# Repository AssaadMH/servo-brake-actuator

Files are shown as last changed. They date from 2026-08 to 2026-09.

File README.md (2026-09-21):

# Fail-Safe Servo Brake Actuator
> A printed drum that lets one servo pull two bicycle brake cables — the mechanical answer to an electrical failure.
`2026` · `OpenSCAD` · `Mechanism design` · `FDM` · `Force analysis`

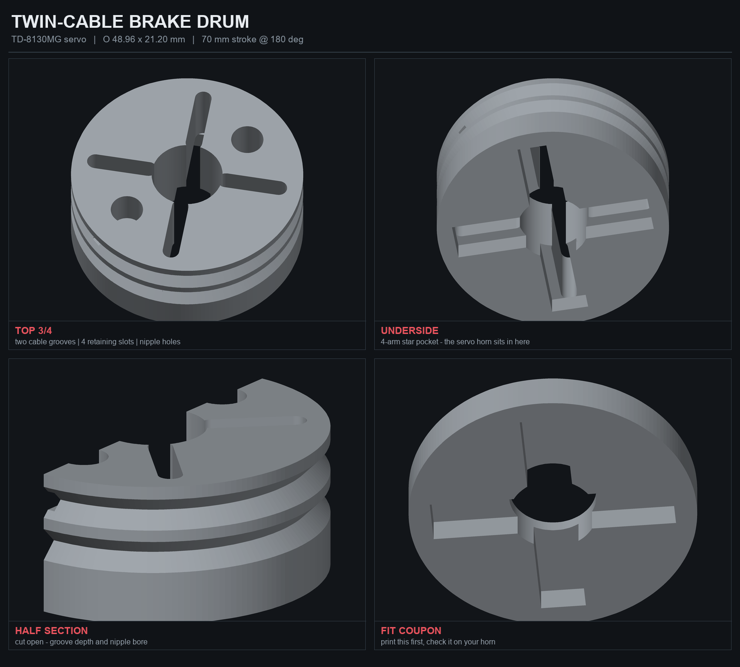
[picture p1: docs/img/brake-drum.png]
Fail-Safe Servo Brake Actuator


## Origin

Built at **IRIS Systems** during a 2026 engineering internship, as part of a team working on
the SHADOW autonomous vehicle programme. This repository covers the parts I worked on; the
wider programme is IRIS Systems' project. Published with their agreement.

## About

After the electrical hold-brake failure on SHADOW, the parking brake had to become purely mechanical. SHADOW was a team project and the failed electrical brake was the team’s work; the mechanical replacement described here is my contribution to it. The first working actuator uses a TD-8130MG servo to pull two bicycle brake cables simultaneously through a printed cable drum.

**The key design decision** is that the drum *captures the servo's stock metal horn* rather than reproducing its 25-tooth spline. A 25T spline printed in PLA strips under load — 30 kg·cm across 0.3 mm teeth on a 6 mm shaft is on the order of 100 kg of shear along the layer lines. A captured horn puts the torque into steel and reduces the plastic's job to holding it in place.

**Force analysis drove the geometry, and it has exactly one governing variable.** At a fixed sweep angle the drum diameter follows directly from the cable stroke, and the pull follows inversely from the diameter — so *stroke sets force, and nothing else does*. That makes the honest way to gain force counter-intuitive: shrink the drum. The current design uses a 44 mm stroke on a Ø30.8 drum for about 6.4 kg per cable in normal working conditions, roughly 10.7 kg at stall. An earlier, larger revision with a longer stroke was weaker for the same servo. Going smaller still is not free either — below about Ø28 the cable groove undercuts the very shoulder the cable nipple pulls against, leaving under a millimetre of plastic to carry the load.

**Both cable anchors sit 180° apart and wind the same way,** so the two pulls cancel as a couple instead of summing into a side load on the servo's output bearing. Cable housing stops and mounting blocks were designed alongside the drum — the pull is taken by a tongue bearing against a groove wall rather than by the clamp bolt — and laid out on a single print plate with a fit-test coupon beside the real part, so one print answers both questions.

**The slicer caught what the CAD did not.** Square cable grooves left the flange above them hanging as an unsupported ring, so they became 90° V-sheaves that self-support — and, as a bonus, seat the cable at exactly the design radius automatically. A second finding is worth keeping: the CAD kernel reported the solid as clean while the exported mesh carried ten non-manifold edges, because a derived dimension landed exactly on another feature's rim. **A kernel saying "simple: yes" does not mean the exported file is sound** — the STL itself has to be checked, which is why every part here goes through an STL sanity script and a G-code verification pass before it reaches the printer.

**The final drum is not servo-driven at all.** The servo version above proved the cable-pull principle, but the production part replaces the white worm wheel inside a Bosch window-lift motor (`0130821xxx`) with a printed wheel that carries the four-cable brake drum on the same hub — so the gearmotor’s own reduction does the pulling. The tooth count was recovered from photographs by unwrapping the rim into polar coordinates and taking a DFT of the tooth frequency: an unambiguous peak at 72. The live part, `gear60_v3`, runs 76 teeth on a 60.80 mm pitch diameter (62.40 mm across the tips), 2.00 mm tooth height and an 8 mm bore, on a split clamping hub with an M3 pinch bolt.

**One number decides whether it fits, and it is still open.** Centre distance follows the *pitch* circle alone, so growing the wheel to 60.80 mm moves the worm 1.60 mm further out — 33.00 mm stock becomes 34.60 mm. Shaving the tooth tips buys none of it back: an earlier revision truncated the addendum and the centre distance did not move at all. Against a 2.00 mm tooth height, 1.60 mm of interference is a jam rather than a tight mesh, so this wheel needs a deliberate housing modification and will not drop into a stock gearbox. That is a known, quantified constraint of the current design rather than a surprise waiting at assembly.

## Figures

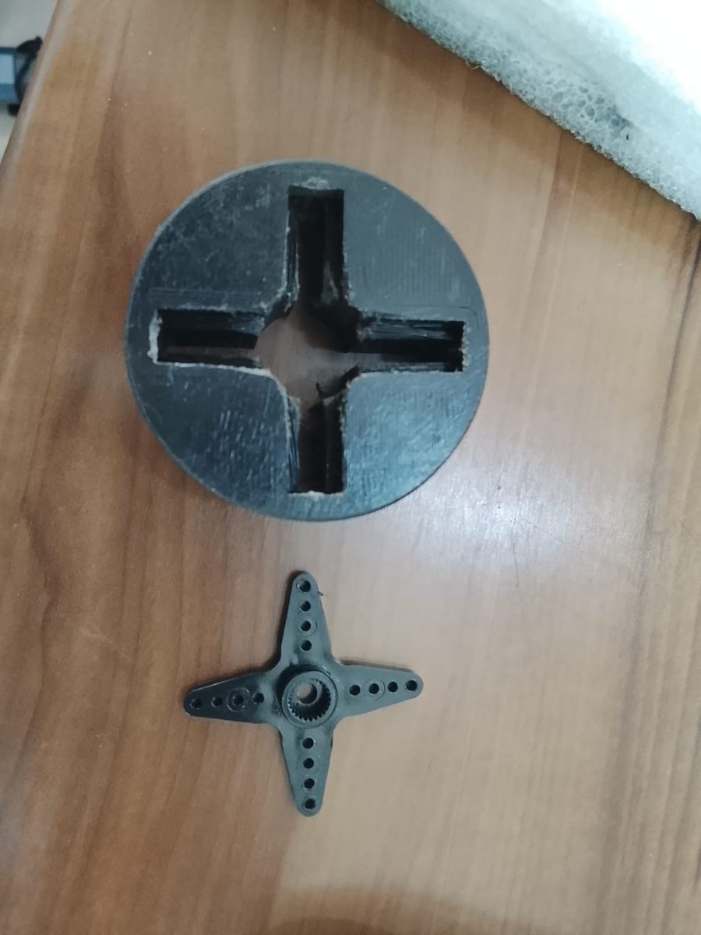
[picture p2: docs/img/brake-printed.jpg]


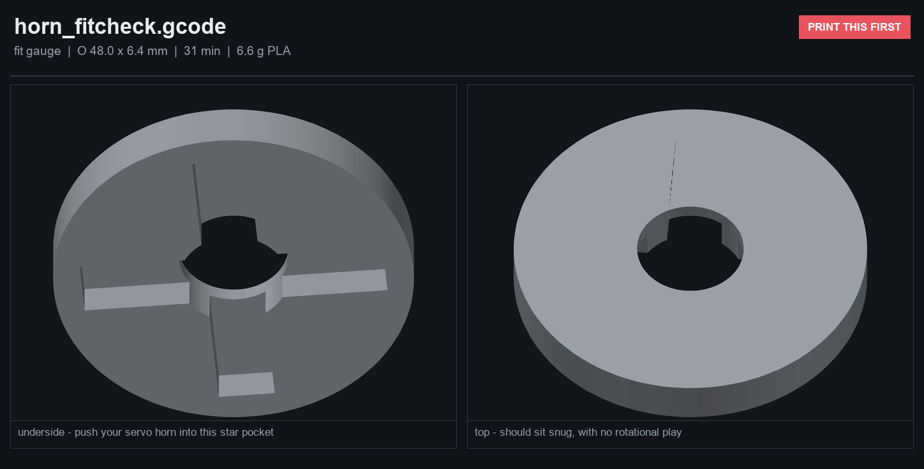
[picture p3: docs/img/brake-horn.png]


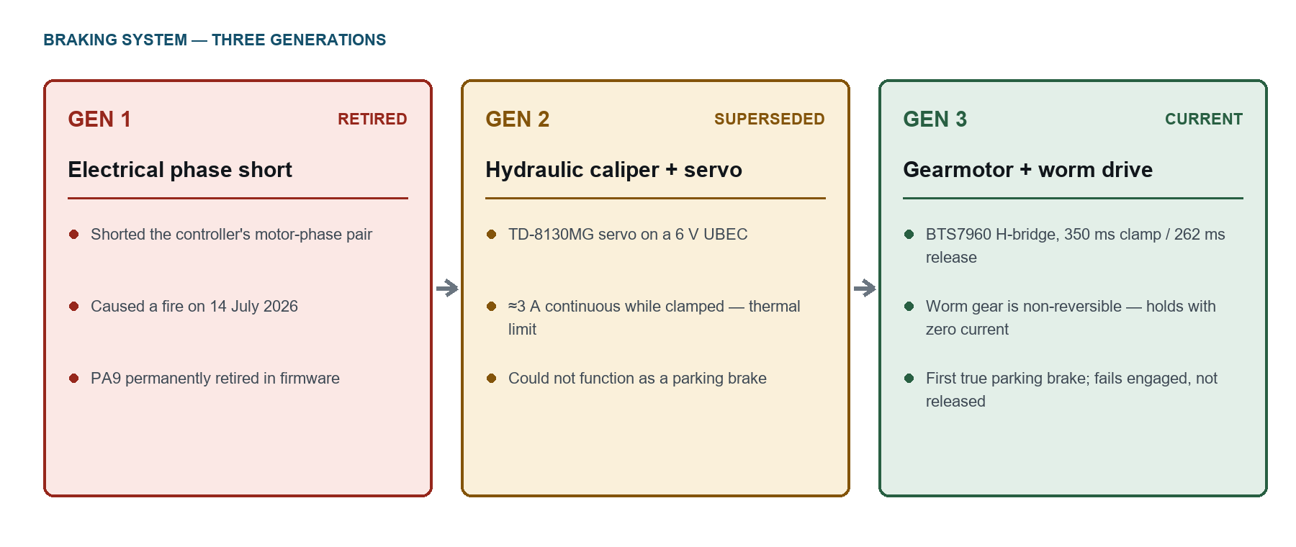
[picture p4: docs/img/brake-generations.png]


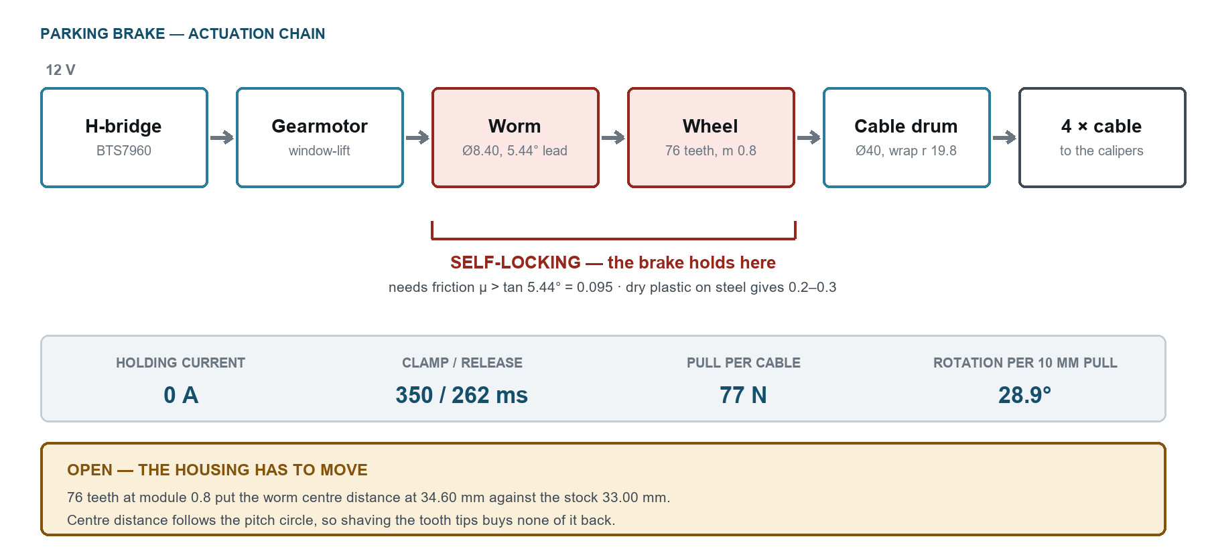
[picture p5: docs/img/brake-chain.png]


## Contents

```
design/
docs/
print/
worm-wheel/
```

## Notes

Not included in this repository: 18 generated/binary file(s), 10 mesh/binary over 2 MB file(s) - build caches, generated toolpaths and oversized binaries are kept out on purpose. The source they are generated from is here.

## Third-party work used here

This work was done as part of a team, and it builds on the following, which are **not** ours and are used under their own licences:

- **OpenSCAD** by OpenSCAD project — <https://openscad.org>

## Author

Lassaad Mahmoudi — <assaadmahmoudi0@gmail.com>  
https://linkedin.com/in/mahmoudi-assaad

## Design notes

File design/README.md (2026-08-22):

# Servo brake-cable drum — TD-8130MG  (rev B)

Pulls **two bicycle brake cables equally**, 70 mm of cable travel over 180° of servo rotation.
Ø47.36 × 19.50 mm. Sliced and ready to print.

## Print these

| File | Profile | Time | PLA |
|---|---|---|---|
| `horn_fitcheck.gcode` | gauge — 0.25 mm, 3 walls, 15 % | 31 m | 6.6 g |
| `servo_brake_drum.gcode` | structural — 0.15 mm, 5 walls, 55 % | 3 h 35 m | 26.0 g |

**Print `horn_fitcheck.gcode` first.** It is only the horn pocket. Push your black star horn into
it — snug, no rotational play. Slop there becomes brake slop later.

If it doesn't fit, measure the horn and edit these four lines at the top of the `.scad`, then
re-render and re-slice:

```
HORN_TIP   = 40.0;   // tip-to-tip across one pair of arms
HORN_ARM_W =  7.0;   // arm width, near the tip
HORN_T     =  4.0;   // arm thickness
HORN_BOSS  = 14.0;   // centre boss diameter
```

`CLR = 0.25` is the per-side clearance — 0.15 if your printer runs loose, 0.35 if it won't go on.

## Everything else in the folder

| File | What |
|---|---|
| `servo_brake_drum.scad` | parametric source, all knobs at the top |
| `servo_brake_drum.stl` / `horn_fitcheck.stl` | meshes — watertight, 1 shell, 0 non-manifold |
| `n2_pla_structural.ini` / `n2_pla_gauge.ini` | PrusaSlicer configs for the N2 |
| `check_stl.py` / `check_gcode.py` | verifiers (manifold + bed extents / E mode / G29) |
| `render_stl.py` / `make_sheet.py` | software renderer → `DRUM_overview.png` |
| `design.html` | the full illustrated spec sheet |

## Rebuilding after a change

```
set PART = "drum" (or "fit" / "cut") in the .scad, then:

C:\Users\HP\lidar_box\tools\openscad-2021.01\openscad.exe -o servo_brake_drum.stl servo_brake_drum.scad
prusa-slicer-console.exe --export-gcode --load n2_pla_structural.ini -o servo_brake_drum.gcode servo_brake_drum.stl
python check_stl.py servo_brake_drum.stl
python check_gcode.py servo_brake_drum.gcode
```

Three traps, all of which bit me here:

- Don't pass `-D` on the PowerShell command line — edit the knob in the file instead. If you script
  a temp copy, write it with `Set-Content -Encoding ascii`; `utf8` adds a BOM and OpenSCAD dies with
  *"Parser error: syntax error, line 1"*.
- **OpenSCAD's STL lands on disk seconds after the process exits.** Verify too quickly and you read
  the *previous* file and get a false confirmation. Check the timestamp.
- CGAL saying `Simple: yes` does not guarantee a clean STL. Run `check_stl.py`.

## What goes together, in order

1. Print the coupon, check the fit on your horn.
2. Screw the **stock star horn onto the servo** with its factory centre screw. That joint carries all
   30 kg·cm — the printed part never touches the spline.
3. Drop the drum over the horn. The star pocket underneath swallows it, rotated 45° from the nipples.
4. Retain with 2–4 M3 screws through the top slots, down into whichever horn holes line up.
   The slots run r = 8…19 mm so any hole pattern works.
5. Load the cables: nipple down its Ø6.6 hole from the top face, wire out sideways into its V.
   Defaults suit **flat-bar / MTB** barrels (6.6 × 8.0). For road pear nipples: `NIP_D = 7.6; NIP_H = 5.0`.

## Why it's shaped like this

- **V-sheaves, not square grooves.** A square groove leaves the flange above it hanging as a 3 mm
  cantilever ring in mid-air — the slicer flagged it as a collapsing overhang. 45° walls hold
  themselves up. Bonus: with the V apex at `R_EFF − CABLE_D/2`, the cable wedges itself at exactly
  the design radius.
- **Ø14.5 bore straight through**, same as the horn boss. A smaller bore leaves an unsupported ring
  at the pocket ceiling with nothing under it to print onto.
- **Nipples 180° apart** so the two ~66 N cable tensions form a couple that cancels, instead of
  adding into a 132 N side load on the servo's output bearing.

## Force budget — read this

| | |
|---|---|
| Servo torque | ~30 kg·cm |
| Cable centreline radius | 22.28 mm |
| Total pull | ~13.5 kg |
| **Per cable** | **~6.7 kg (66 N)** |

6.7 kg is a firm hand squeeze — **enough to pull a brake lever at the handlebar**, which is what a
70 mm stroke implies. **Not** enough to drive a caliper directly (a caliper wants 15–25 kg but only
~15 mm of travel).

If it's weak, shorten the stroke: `STROKE = 35` halves the drum and doubles the pull to ~13 kg per
cable. Every other dimension derives from that one number.

## You still need cable housing stops

This part only pulls the inner wire. The outer housing must be anchored to the aluminum plate at a
fixed point, aimed tangentially at each groove level. Without those two stops the housing just
compresses and nothing moves. **Not designed yet.**

## PLA caveat

PLA creeps under sustained load and softens near 55 °C. If this holds the brake applied for long
stretches, or lives in a closed enclosure, re-slice in PETG — same geometry, no changes.

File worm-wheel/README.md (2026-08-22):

# gear60 — 60 mm gear, Ø7 mm bore, 2.0 mm tooth height

Replacement for the white worm-wheel out of the Bosch window-lift motor
(`0130821xxx`) in the photos.

## Files

| File | What it is |
|---|---|
| `gear60.scad` | The parametric source — change everything here |
| `gear60_v2.scad` / `.stl` | ★ **CURRENT** — tip 60.60, bore 8, cable stations 20 mm higher, open cable chute. See [v2](#v2--gear60_v2scad). Print file `gear60_v2.gcode`. **Still needs the worm moved 0.8 mm.** |
| `cap60.scad` / `.stl` | ★ **Retaining cap** for the v2 drum — closes the open nipple pockets. Clamps on, needs no gear change. See [the cap](#the-retaining-cap--cap60scad). Print file `cap60.gcode` + one M3×14. |
| `test_cap_fit.scad` | Clash-checks the cap against the real exported gear mesh |
| `v2_profile.ini` | The PETG profile dumped out of the shipped v2 gcode — slice everything with this |
| `test_cable_route.scad` | Proves a cable can actually be fitted (needs a generated `_v2_sandbox.scad` — see [Re-generating](#re-generating)) |
| `gear60_drum4.stl` | Helical RH + 4-cable brake drum, the original 22 mm-tall part |
| `gear60_d608.scad` / `.stl` | Superseded by v2. Tip dia grown to 60.80 mm (z 74) — see [Bigger-OD variant](#bigger-od-variant--gear60_d608scad) |
| `gear60_d62.scad` | Superseded first pass at the above (z 76, tip 62.40). No STL. |
| `gear60_z72_m0.8_helical_RH.stl` | Plain wheel, helical 5.44° RH, no drum |
| `gear60_z72_m0.8_helical_LH.stl` | Same, left hand — if the worm turns out left-handed |
| `gear60_z72_m0.8_spur.stl` | Straight-cut fallback (helix 0) |
| `gear60_z72_m0.8_helical_RH_grub.stl` | Grub-screw hub instead of the clamp |
| `test_clamp.scad` | Geometric self-tests for the clamp (see below) |
| `preview_top/iso.png` | Renders |

Shaft is smooth, so the hub is a **split clamp with an M3 pinch bolt**.
See [The split clamping hub](#the-split-clamping-hub).

## What was measured from the photos

The rim was unwrapped into polar coordinates and the tooth frequency
extracted by DFT. The peak is unambiguous at **k = 72** across three
different sample radii (r = 840, 855, 870 px), so:

> **the original gear has 72 teeth.**

Teeth are fine-pitch, driven by the worm on the armature shaft. The
photos give no absolute scale, so the module was inferred from the tooth
count and then **confirmed by caliper** — see
[Module: CONFIRMED](#module-confirmed).

## The numbers — `gear60_z72_m0.8_helical_RH.stl`

Verified by re-reading the exported mesh, not from the script's own echo:

```
tip (outside) diameter   59.200 mm     <- matches the measured original
root diameter            55.200 mm
tooth height (whole)      2.000 mm
pitch diameter           57.600 mm
teeth                    72
axial module   m_x       0.80000       <- confirmed, 59.2 / 74
normal module  m_n       0.79640       <- derived, m_x * cos(helix)
helix angle              5.4403 deg    <- from the measured worm
helix hand               right (assumed - CHECK)
pressure angle           20°
circular pitch            2.513 mm
body bore                 7.20 mm  (7.0 + 0.20, non-gripping section)
clamp bore                7.10 mm  (7.0 + 0.10, this is what grips)
face width               10.00 mm
hub diameter             22.00 mm
total height             22.00 mm  (10 gear + 12 clamping hub)
slit                      1.20 mm wide, out to r = 18.5
jaw wall at the bore      7.45 mm
```

`ded_f = 1.5` is what buys the 2.00 mm depth — a standard 1.25 dedendum
would give 1.80 mm. On a worm drive a deeper root only adds tip
clearance, so this is safe either way.

Rebuild a z = 73 / Ø60.00 variant with `-D 'z=73'` if you ever want the
literal 60 mm for something else.

---

## The split clamping hub

The hub is a **C in cross-section**, 22 mm tall overall with 12 mm
projecting above the gear face. A 1.2 mm radial slit runs from the bore
out through the side, and an M3 socket-head pinch bolt pulls the two jaws
together. Friction round the whole shaft, no shaft modification needed.

```
   top view of the hub                side view
   ─────────────────────              ──────────
        ╭───────╮                     ┌────────┐  ← clamp hub, 12 mm
      ╭─┤ Ø7.1  ├─╮  ╔══╗       ══════┤        ├══════   z = 10..22
      │ │ bore  │ │══╣▓▓║ ear   teeth ▐└───┬──┘▌         z = 0..10
      ╰─┤       ├─╯  ╚══╝                Ø7.2 bore
        ╰───────╯     ↑
         ← slit →   M3 pinch bolt
         (1.2 mm)   crosses the slit
```

- Slit reaches **r = 18.5 mm**; the tooth roots start at r = 28 mm, so it
  never touches a tooth. The gear stays a full, unbroken 72-tooth ring —
  which is why the slit stops at the hub instead of running out through
  the rim the way a split pulley usually does.
- The slit root ends in a **Ø3 rounded relief** rather than a sharp
  corner. That is the crack starter on a printed part, so it gets a
  radius instead of an edge.
- The bolt seats land on **flat, parallel pads** (the stadium-shaped ear),
  not on the curved hub — Ø6.4 counterbore for the head on one side,
  Ø4.0 × 5 mm heat-set insert seat on the other.
- The clamp bore is **7.10 mm** while the gear body bore is 7.20 mm. The
  body section is deliberately looser so the clamp does the gripping and
  the gear still slides on easily.

### Why this beats the grub screws

Grub screws point-load two spots and dent the shaft; a clamp grips the
full circumference by friction. On a smooth shaft that is worth several
times the holding torque, and it does not chew up the shaft — so you can
still take it apart and reposition it.

### Fitting

1. Set the M3 insert in the ear (soldering iron ~200 °C for PETG, in
   slowly and straight).
2. Slide the gear on **with the bolt loose** — it should be a light slip
   fit. Do not force it; if it is tight, ream the bore rather than
   hammering, or raise `clamp_clear`.
3. Tighten the M3 gradually to roughly **1–1.5 Nm**. It will feel solid
   well before the 1.2 mm gap closes — the gap is *supposed* to stay
   partly open. If it bottoms out metal-to-metal before it grips, your
   bore printed oversize; drop `clamp_clear` to 0.05 and reprint.
4. Threadlock it. Car doors vibrate.

**Print it teeth-down, hub up.** That is not just about supports: the
C-section flexes circumferentially, so the bending stress runs *along*
the layers rather than trying to peel them apart. Printed on its side
this joint would delaminate at the back of the C.

### Verification

`test_clamp.scad` checks the things that are easy to get silently wrong,
each paired with a control probe that must give the opposite answer — a
probe that misses the part entirely would otherwise read as a pass:

| Test | Checks | Expect | Control | Expect |
|---|---|---|---|---|
| 1 | slit fully separates the jaws | empty | 2 | solid |
| 3 | head counterbore breaks through the flat | empty | 33 | solid |
| 4 | insert seat breaks through the far flat | empty | 44 | solid |
| 5 | ear stays clear of the tooth roots | empty | 55 | solid |

```bash
for T in 1 2 3 33 4 44 5 55; do "$OS" -D "TEST=$T" -o t.stl test_clamp.scad; done
```

All eight pass on the shipped geometry.

### Still want grub screws?

`hub_style = "grub"` gives 2 × M3 radial screws at 120° instead
(`gear60_z72_m0.8_helical_RH_grub.stl`). If you go that route, file two small flats
on the shaft where the tips land — otherwise it will spin under a stalled
worm.

---

## Module: CONFIRMED

Measured original tip diameter: **59.2 mm**, over the 72 teeth counted
from the photos.

```
m_n = OD / (z + 2) = 59.2 / 74 = 0.800   exactly
```

`m_n = 0.8` was an inference; it is now a measurement, and the two agree
to three decimal places. Tooth size is settled — **use the z = 72 file**.

That also means your "60 mm" was a rounded read of a 59.2 mm gear, and
"2 mm tooth height" of a standard 1.8 mm one (2.25 × 0.8). The shipped
`ded_f = 1.5` cuts the root 0.2 mm deeper than standard. That is
deliberate and safe on a worm drive — a deeper root only adds tip
clearance, it cannot cause interference. The addendum, which is what
actually sets the mesh, is fixed by the 59.2 mm tip diameter.

Derived, all now confirmed:

```
teeth            72        module      0.80
tip diameter     59.20     pitch dia   57.60
root diameter    55.20     base dia    54.13
circular pitch    2.513    ratio       72:1 with a single-start worm
```

## Helix: RESOLVED

Worm measured: **single start, 10.00 mm outside diameter.**

The lead angle is defined on the worm's **pitch** diameter, not its
outside diameter, and it uses the **axial** module:

```
d1    = worm_OD - 2*m_x       = 10.00 - 1.60      = 8.40 mm
helix = atan(starts * m_x / d1) = atan(0.8 / 8.4) = 5.4403 deg
```

> ### Correction
> An earlier version of this file gave 4.6 deg for a 10 mm single-start
> worm. That was wrong: it used the worm's **outside** diameter in place
> of its pitch diameter, and the normal module in place of the axial one.
> Both errors bias the angle low. The correct value is **5.4403 deg** —
> 0.87 deg higher. The table it came from is removed rather than
> corrected: the real worm is measured now, so the table is moot.

### What changed in the model

The tooth is now cut about the **axial / transverse** module, which is
the quantity that has to match the worm:

```
m_x  (axial = transverse)   0.80000   <- measured, must match the worm
m_n  (normal, derived)      0.79640   = m_x * cos(helix)
helix                       5.4403 deg, right hand (assumed)
twist over the 10 mm face   1.8947 deg
```

`m_x` is now the input and `m_n` is derived — the file previously had
that the wrong way round, which would have thrown the tip diameter
0.18 mm out as soon as a helix was applied. All three targets still land
exactly: tip 59.200, root 55.200, tooth height 2.000.

`slices` also no longer bottoms out at 2 for a small twist, which had
been leaving the helical flank as two straight bands. It is driven off
the face width now (351 z-levels in the mesh instead of 3).

### Verified in the mesh

The tooth phase was measured at the bottom face and again at the top,
as a circular mean folded into one 5 deg tooth pitch:

| Build | Measured twist, bottom -> top |
|---|---|
| helical RH | +1.8947 deg (counter-clockwise rising = right hand) |
| helical LH | -1.8947 deg (exact mirror) |
| spur | +0.0000 deg |

Predicted 1.8947 deg. Magnitude matches to four decimals, the hand
mirrors, and the spur control sits at zero.

### WARNING — hand is the one thing left to check

**A right-hand wheel will not mesh with a left-hand worm.** The hand is
not visible in your photos, so both are built.

Look at the worm from the side: if the threads climb left-to-right like
an ordinary screw or bolt, it is **right hand** -> use
`gear60_z72_m0.8_helical_RH.stl`. If they climb right-to-left, use the
`_LH` file. Most automotive worms are right-hand, which is why RH is the
default — but check, do not assume.

If you would rather not gamble, print `gear60_z72_m0.8_spur.stl` first as
a test fit. It will turn against either hand, just noisily.

### Honest limitation

This is a **cylindrical helical wheel, not a throated (globoid) one**. A
proper worm wheel is hollowed to wrap around the worm, giving line
contact along the thread. This one meets the worm on a short contact
patch instead. That matches what the original appears to be — its rim
looked flat in your photos, not throated — and a throated form is not
realistically printable at 0.8 module. It is the reason to expect a
service life below the moulded original's.

### Which STL?

**`gear60_z72_m0.8_helical_RH.stl`** — dimensional match to the original
(same 72 teeth, same module, same tip diameter, so ratio and centre
distance are unchanged) plus the 5.4403 deg helix the measured worm
calls for. Right hand.

Swap to `_LH` if the worm turns out left-handed, or `_spur` for a
hand-agnostic test fit.

A 73-tooth / 60.00 mm variant is no longer shipped — it only made sense
while 60 mm was believed to be the target. Rebuild it with
`-D 'z=73'` if you ever want it; note the extra tooth pushes the pitch
radius out 0.4 mm and will bind in the stock housing.

---

## Brake cable drum — 4 cables

Turns the wheel into a parking-brake actuator. The worm drive is
self-locking, so it holds cable tension with the power off.

```
                    stations at 45 / 135 / 225 / 315 deg
              nipple pocket d7.6              cable groove
                     |                             |
        z=22  _______v_____________________________v____
             |   o       o                              |  <- drum skirt
             |         COLLAR d22 (clamp)               |     d40, wall 3.5
   groove -> |=========================================||     
        z=13 |______   web 3.0   ______________________|
   gear face |################ GEAR BODY ##############|  z=10
        z=0  |#########################################|
```

| | |
|---|---|
| Drum outside dia | 40.00 mm |
| Skirt wall | 3.50 mm |
| Cable groove | 2.60 wide x 1.00 deep, floor at r 19.0 |
| Effective wrap radius | 19.8 mm |
| Nipple pocket | d7.6 x 9 deep, centre r 14.8, opens at the top face |
| Wire slot | 2.4 wide, tangential, at groove level |
| Stations | 4, at 45 / 135 / 225 / 315 deg |
| Rotation for 10 mm pull | 28.9 deg |
| Overall height | 22.00 mm — unchanged |

Stations sit at 45 deg so they stay clear of the slit and the bolt
access window, both at 0 deg. At 28.9 deg of travel and 90 deg spacing,
no cable ever reaches its neighbour's station.

### Two things the geometry forced

**The drum is a skirt, not a solid boss.** Growing the hub to a solid
d40 would take the clamp jaw wall from 7.45 to 16.45 mm. Closing
stiffness goes as t^3, so that is **10.8x stiffer** — the M3 pinch bolt
would never move it. The clamp collar stays at d22 and the drum is a
3.5 mm skirt tied to it by a 3 mm web, so the part that has to flex is
still the slim one.

**Each station needs a boss.** Above the web, the space between the d22
collar and the d33 skirt bore is open air. A pocket cut there would not
be a socket at all — the nipple would sit loose in a gap. Each station
gets a local boss spanning collar to skirt, which also ties the skirt
back in.

The slit and the bolt counterbore both run out through the skirt. They
have to: a slit that stops at the collar would leave the skirt welding
the jaws shut, and a bolt with no window would be unreachable.

### Force and stroke

Cable tension is torque / 19.8 mm, shared over 4 cables:

| Gear torque | Total pull | Per cable |
|---|---|---|
| 2 Nm | 101 N | 25 N (2.6 kgf) |
| 4 Nm | 202 N | 51 N (5.1 kgf) |
| 6 Nm | 303 N | 77 N (7.7 kgf) |
| 8 Nm | 404 N | 101 N (10.3 kgf) |

Shrink `drum_d` for more force and less stroke; the two trade directly.

### Self-locking margin — check this

The brake holds with the power off only while the worm cannot be
back-driven. That needs friction coefficient > `tan(5.44 deg)` = **0.095**:

| mu | Friction angle | |
|---|---|---|
| 0.05 well-greased steel/steel | 2.9 deg | **BACK-DRIVES** |
| 0.10 greased steel/plastic | 5.7 deg | holds, barely |
| 0.15 lightly oiled | 8.5 deg | holds |
| 0.25 dry steel/plastic | 14.0 deg | holds |

**The margin is thin.** A 5.44 deg lead sits right on the boundary, so do
not over-grease the worm. A plastic wheel on a steel worm runs at
mu 0.2-0.3 dry and holds comfortably; flood it with low-friction grease
and it can creep. Test it loaded before trusting it as a parking brake.

### Cable tensioning

The pear nipple seats in a fixed pocket, so tension is not adjusted at
the drum. That is normal and correct — set it at the caliper end, where
the bare wire is clamped, and use a standard **inline barrel adjuster**
per cable for fine independent trim. Roughly 10 mm of adjustment each,
which matches the stroke.

Stepped seats in the drum were considered and rejected: a d7.0 nipple
needs seats 8 mm apart to stay distinct, and 8 mm steps are useless
against a 10 mm stroke. A printed threaded adjuster was rejected too —
it would put the full brake load on a plastic thread.

### Assembly

Feed each wire in through the slot from the drum surface, then drop the
nipple into its pocket from the top. The slot is a buried channel at
groove level, so the wire stays captive once seated.

### Verification

| Probe | Checks | Expect | Control | Expect |
|---|---|---|---|---|
| 10 | Nipple pocket is a real socket | empty | 100 | solid |
| 11 | Wire slot reaches the drum surface | empty | 110 | solid |
| 12 | Skirt sits on solid material | solid | 120 | empty |
| 13 | Hex key reaches the pinch bolt | empty | 130 | solid |

All pass, alongside the original 8 clamp probes.

---

## Bigger-OD variant — `gear60_d608.scad`

Tip dia **60.80 mm**, up from 59.20. At `m_x = 0.8` the tip diameter only
moves in **1.60 mm steps** (one whole tooth adds `2*m_x`), and the module
is the one number that must stay 0.8 to match the worm — so 60.80 is not
an approximation, it is exactly `z = 74`:

| | stock `gear60_drum4` | `gear60_d608` |
|---|---|---|
| teeth | 72 | **74** |
| tip dia | 59.20 mm | **60.80 mm** (+1.60) |
| pitch dia | 57.60 mm | 59.20 mm |
| root dia | 55.20 mm | 56.80 mm |
| module / pressure angle | 0.8 / 20° | unchanged |
| helix | 5.4403° RH | unchanged (twist re-derived, −1.84°) |
| tooth height | 2.00 mm | unchanged |
| bore, hub, clamp, drum | — | all unchanged |
| overall height | 22.00 mm | 22.00 mm |
| ratio with a 1-start worm | 72:1 | 74:1 |
| slice (same PETG profile) | 3 h 29 m, 9756 mm | 3 h 33 m, 9958 mm |

**This still breaks the stock mesh.** Worm centre distance is
`(d_worm_pitch + d_wheel_pitch)/2` = `(8.40 + 57.60)/2` = **33.00 mm**
stock, but **33.80 mm** here. The worm must move **0.80 mm** further from
the wheel axis (or the wheel shaft moves the same amount). That is half
the shift of the abandoned 62.40 version, but 0.80 mm of interference
against a 2.00 mm tooth height is still a jam, not a tight mesh. No
amount of gear geometry absorbs it — it is a housing change.

The variant is a 3-line file that `include`s `gear60.scad` and overrides
`z`, so the base design stays the reference part.

### The z=74 degeneracy — fixed in `gear60.scad`

z=74 originally rendered at **genus 12** where 72, 73, 75 and 76 all gave
13. `stlcheck` found why: a **second shell — 6 triangles, zero volume, at
z=10.00, x=16.50**, i.e. exactly on the gear top face at the drum skirt's
inner wall. The drum lands *on* the gear face, so the skirt, web and boss
bottoms were all coplanar with the gear top: three coincident faces in one
union, and at that particular tooth count the tessellation threw off a
flake.

`drum_body()` now sinks the drum `eps = 0.01` into the gear (heights carry
the same `+eps`, so the top face stays at exactly 22.00). The overlap is
buried in solid material — **volume is unchanged at 31185.94 mm³ for the
stock part** — and 72/73/74/75/76 now all render as one shell, genus 13.
Another instance of the rule from the drum project: *keep derived
dimensions from coinciding exactly.*

All 16 probes in `test_clamp.scad` return identical results for z=72 and
z=74, controls included. The "long bridging extrusions" slicer notice is
the drum web and appears on the stock part too.

**Note on probe 4.** It reports *solid* where the table below says empty —
on the stock gear as well. Not a defect: the probe runs outward from the
ear flat at x=12 and clips the **315° cable boss**, which was added after
these 8 clamp probes were written. With `drum=false` probe 4 is empty, so
the insert seat is open as designed.

---

## v2 — `gear60_v2.scad`  (2026-08-08, current print file)

Four changes on top of `d608`. Print file: **`gear60_v2.gcode`**, 5 h 32 m,
38.36 cm³ (~49 g PETG), 42 mm tall.

| | `gear60_d608` | **`gear60_v2`** |
|---|---|---|
| teeth | 74 | 74 (unchanged) |
| **tip dia** | 60.80 mm | **60.60 mm** |
| addendum factor | 1.000 | **0.875** |
| pitch dia | 59.20 mm | 59.20 mm (unchanged) |
| root dia | 56.80 mm | 56.80 mm (unchanged) |
| tooth height | 2.00 mm | 1.90 mm |
| **bore (nominal shaft)** | 7.0 | **8.0** → 8.20 body / 8.10 clamp |
| jaw wall at bore | 7.45 mm | 6.95 mm |
| **hub_ext / total height** | 12 / **22 mm** | 32 / **42 mm** |
| **groove (cable) height** | z = 16 | **z = 36** (+20) |
| nipple pockets | z 13…22 | z 33…42 |
| pinch bolt | z = 16 | z = 26 |
| **cable loading** | closed tunnel | **open chute to the top face** |
| slice | 3 h 33 m | **5 h 32 m** |

### 1. Why 60.60 is an addendum change, not a tooth change

`m_x = 0.8` is the worm's axial module and cannot move; tooth count moves
the tip dia in 1.60 mm steps, so **60.60 is unreachable by adding teeth**.
It is reached by truncating the addendum instead — `add_f 1.000 → 0.875`
takes 0.10 mm off every tooth tip:

```
tip   60.80 → 60.60      pitch 59.20 → 59.20 (UNCHANGED)
root  56.80 → 56.80      tooth ht 2.00 → 1.90
```

**Consequence to be clear about: this does not fix the mesh problem.**
The pitch circle is what sets centre distance, and it did not move — the
worm still has to sit at **33.80 mm** instead of the stock 33.00 mm. The
0.80 mm housing shift from the d608 version is still outstanding. Shorter
tips relieve *tip* interference very slightly and nothing else.

### 2. Bore 8 mm

`bore_d` is the **nominal shaft** size, so the part comes out 8.20 through
the gear body and 8.10 in the clamp section, which then pinches down onto
a true 8.00 shaft. Same convention the 7 mm version used (7.20 / 7.10).
If the requirement is instead that the *hole measure* 8.00, set
`bore_d = 7.9`.

### 3. Cable stations 20 mm higher

The whole collar grows — `hub_ext 12 → 32` — so the skirt, the ear, the
slit and the four bosses all travel up together and the part is 42 mm
tall. The groove follows (`groove_z 16 → 36`) and the nipple pockets stay
9 mm down from the top face. The pinch bolt lands at z = 26, which also
gets it out of the groove it used to share a height with.

**Watch the overturning moment.** 4 × ~66 N now pulls 36 mm above the gear
face instead of 16 mm — roughly **2.2× the tilting moment** on an 8 mm
shaft and on a single M3 pinch bolt. If the collar ever cocks or walks on
the shaft, that is the reason, and a second pinch bolt higher up the
collar is the fix.

### 4. A route the cable can actually get in by — `wire_entry`

The first build could not be cabled by hand: the nipple pocket was blind
from the top and the wire slot was a **closed tunnel** at groove level, so
the only way in was to thread the free end of the cable in from outside
and pull the nipple down the pocket.

`wire_entry = true` (new in `gear60.scad`, now the default) runs that same
tangential slot on up to the top face as an open 2.4 mm chute. Drop the
nipple down its pocket, let the wire fall sideways into the notch, and it
seats itself in the groove.

The anchor is not weakened where it matters: the nipple is Ø7.0 against a
2.4 mm gap, so it still cannot escape sideways, and the load is still
carried by the two 2.6 mm lands either side of the slot — which is where
it was carried before. Only the material *above* the slot is gone, and it
was never in the load path (the pull is horizontal).

### Verification

- **1 shell, solid, 51 355.13 mm³**, bbox exactly 60.60 × 60.60 × 42.00
  (`stlcheck.py`).
- **Genus 3 at z = 73, 74 and 75** — stable across neighbours, so no
  repeat of the z=74 flake. (13 → 3 is expected: 8 handles disappear when
  the four wire tunnels become open notches, and 2 more when the groove
  moves away from the pinch-bolt counterbore.)
- `test_cable_route.scad` sweeps both loading motions — the Ø7.0 nipple
  falling down its pocket and the 1.6 mm wire falling down the chute —
  and intersects them with the part. **Empty = the route is clear.**
  It is proven sensitive: re-render the sandbox with `wire_entry=false`
  and it returns **4 × ~66 mm³ of obstruction at z 37.30…42.00**, exactly
  the roof the chute removes.
- Slicer profile is the one dumped out of `gear60_drum4_d608.gcode`;
  re-slicing the d608 STL with it reproduced the shipped **3 h 33 m 12 s**
  exactly, so it is a faithful control. v2 gcode verified on-bed
  (113–187 mm of a 300 mm bed), absolute E, no G29, top layer at 42.00.

---

## The retaining cap — `cap60.scad`  (2026-08-11)

`wire_entry = true` deliberately took the roof off the four nipple pockets
so the cables could be dropped in by hand. Nothing then stops a nipple
lifting back out when its cable goes slack. `cap60` closes them.

**It needs no change to the gear.** It clamps onto features that already
exist on `gear60_v2` as printed. Print file: **`cap60.gcode`**, 32 m 28 s,
4180.72 mm³, plus one **M3 × 14** screw.

| | |
|---|---|
| lid | OD 44.30, ID 22.60, 2.40 thick — sits on the top face at z 42.00 |
| skirt | bore 40.30 (0.15 radial slip on the Ø40 drum), 4.20 tall |
| skirt occupies | part z **37.80…42.00** — 0.50 clear of the groove top |
| split | 1.80 gap at **180°**, deliberately not at the gear slit's 0° |
| lugs | 6.00 × 6.00, 13.80 across the pair, M3 Ø3.40 / Ø2.90 thread-forming |
| lead-in | 0.60 chamfer at the skirt mouth |

### Why it clamps from outside

The collar is a **split clamp**. Anything gripping the drum rigidly and
bridging the slit stiffens the jaws and stops the M3 pinch bolt gripping
the shaft — the same reason the drum is a thin skirt and not a solid boss.
Clamping the *outside* squeezes in the **same direction the pinch bolt
works**, so it assists rather than fights, and the cap is itself split, so
it is a C-clip and not a hoop.

The centre is left open (ID 22.60), so it does not matter whether the
shaft protrudes past the top face or stops short of it.

There are only 4.70 mm of clean drum OD to grip — z 37.30 (groove top) to
42.00 — and nothing at all lives outboard of r 20 in that band. The
pinch-bolt counterbore does exit at y = 22, but at z = 26, eleven
millimetres below.

### ★ The wire chute is TANGENTIAL, not radial

The first cut of this cap keyed itself with a tab at each station angle,
dropping into the wire chute. `test_cap_fit.scad` rejected it —
**4 × 8.73 mm³ of interference at exactly 45/135/225/315, z 37.80…42.00.**

`gear60.scad` builds the chute as

```
translate([nip_r,0,z]) rotate([0,0,90]) translate([0,-w/2,0]) cube([r_o+4,w,h])
```

which is the strip **x 13.60…16.00, y 0…24** — it leaves the pocket
*sideways* in +Y and only crosses the OD **36.87°…47.16° away from its own
station**. At the station angle the drum OD is solid material. "Leaves the
pocket tangentially" in the source comment meant exactly that.

Tabs are off (`tabs = false`). Keying it properly would need an oblique
slab following those walls, for no gain: the cap is an annulus, so it
covers all four pockets at any rotation, and the M3 lug is what retains it.

### Verification

- Cap mesh: **1 shell, solid, 4180.72 mm³**, bbox 6.60 tall (`stlcheck.py`).
- `test_cap_fit.scad` intersects the cap, at its seat, with the **real
  exported gear mesh** — not with a re-derived model. **Empty**: every
  component comes back at 0.00 mm³, which is the lid underside resting
  coplanar on the top face at z = 42.00, as intended.
- **Proven sensitive**: `-D drop=1.5` sinks the cap into the cable groove
  and it returns **636 mm³ across 9 bodies**. Without that control an
  "empty" result would mean nothing.
- Sliced from `v2_profile.ini`, the profile dumped out of the shipped v2
  gcode, so the cap prints on the same settings as the gear.

### Assembly

Cable the drum as before, drop the cap on, and nip the M3 up until it
stops turning by hand. It lifts straight off again to re-cable. Do not
overtighten — the drum skirt is only 3.5 mm thick and the job is retaining
a slack nipple, not carrying load.

---

## Re-generating

```bash
OS="/c/Users/HP/Tools/openscad-nightly/OpenSCAD-2026.07.20-x86-64/openscad.exe"
"$OS" --backend=Manifold -D 'm_n=0.82' -D 'z=72' -D 'helix=8' \
      -o gear_custom.stl gear60.scad
```

Every parameter is overridable with `-D`. The script echoes the resulting
pitch/tip/root diameters and tooth height so you can check them before
slicing.

## Printing

- Print **flat on the toothed face**, no supports. The web recess and the
  bore are the only overhangs and both are vertical.
- 0.12–0.16 mm layers. At 2.51 mm circular pitch the teeth are small —
  a 0.4 mm nozzle is the practical floor, 0.3 mm is better.
- 4+ perimeters, ≥40 % infill. The rim wants to be solid: `rim_wall = 3`
  already forces ~3 mm of solid material under the tooth roots.
- **PETG or ABS/ASA, not PLA** — this lives next to a motor in a car door.
  PLA will creep under the worm's tooth load and soften in summer heat.
  Nylon would be better still if you can print it.
- `bore_clear = 0.20` suits a well-tuned printer. If your holes come out
  tight, raise it; if the shaft is loose, drop it to 0.10 and ream.
- The pinch-bolt hole is **horizontal**, so its top surface will sag a
  little. Run a 3.4 mm drill through by hand before assembly — a few
  seconds, and the bolt then pulls square instead of cocked.
- Do **not** print the slit with a brim or blob bridging it. Check it is
  actually open before you fit the gear; a slit fused shut by a stray
  first-layer skirt turns the clamp into a solid hub.
- `clamp_clear = 0.10` is tight by design. Print the gear body first if
  you want to test-fit, or raise it to 0.15 if your holes run small.

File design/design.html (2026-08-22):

Printed part · Servo actuator · Rev B · 21 Jul 2026 · Sliced, ready to print

# Twin-cable brake drum

A printed drum that sits on a TD-8130MG servo and pulls two bicycle brake cables at once, equally. One turn of the servo, 70 mm of cable. The stock star horn is swallowed inside it, so the servo's factory spline takes the torque and no printed plastic ever touches the shaft.

Outside Ø

47.36 mm

Height

19.50 mm

Stroke

70 mm

Sweep

180°

Print time

3 h 35 m

Filament

26 g PLA

Rev B — the slicer caught two things I got wrong

Square grooves became 90° V-sheaves. A square channel left a 3 mm ledge hanging in mid-air above each groove, all the way around — the slicer called it a collapsing overhang and it would have drooped. V-walls at 45° hold themselves up, and the cable now self-centres at exactly the design radius.

The centre bore grew to Ø14.5 and runs straight through. The old Ø9 bore left a thin unsupported ring at the pocket ceiling with nothing under it to print onto. Matching the bore to the horn boss removes the ring entirely.

Both parts now slice with zero support warnings.

## 01 The part

Two stacked V-sheaves, two nipple pockets 180° apart, four retaining slots, and a star-shaped pocket underneath. Mesh verified watertight, single shell, zero non-manifold edges.

Three-quarter view of the drum from above, showing two cable grooves around the rim, four radial retaining slots, the central bore and two nipple holes.

Top ¾ — grooves, nipple pockets, retaining slots

View of the underside showing a four-arm star-shaped pocket that receives the servo horn.

Underside — the star pocket that grips the horn

Half of the drum cut away, showing the two grooves in cross section and a nipple bore running down from the top face.

Half cut away — how deep the pockets run

A thin test coupon containing only the star-shaped horn pocket.

Fit coupon — print this one first

## 02 Section through the cable plane

Cut vertically through both nipple pockets. Note the asymmetry — it is deliberate. The right-hand nipple feeds the lower groove, the left-hand one feeds the upper groove, so the two cable tensions sit on opposite sides of the shaft and cancel instead of adding.

1. 1Nipple pocket, Ø6.6. Drop the barrel nipple in from the top face; it seats at groove height.
2. 2Wire slot into the lower V. The wire leaves the nipple sideways. The red dot is where it seats — the V is exactly cable-width at Ø44.56, so the drum sizes itself.
3. 3Second pocket, opposite side. Shallower, because it feeds the upper V.
4. 4Ø14.5 bore, straight through. Same size as the horn boss. A screwdriver reaches the servo's centre screw after assembly.
5. 5Horn pocket, 4.4 deep — dashed, because the arms sit at 45° and are behind this cut. Four retaining slots follow the same 45°.

## 03 Stroke sets the force

This is the whole trade, and it is worth understanding before printing. The drum diameter is fixed entirely by how far you want the cable to travel. Bigger drum, longer pull, weaker pull — there is no way around it short of a stronger servo or gearing.

Stroke per cable | Drum Ø | Total pull | Per cable | Verdict
70 mm | 44.56 | 13.5 kg | 6.7 kg | Chosen. Enough for a handlebar lever, not a caliper.
40 mm | 25.46 | 23.6 kg | 11.8 kg | Comfortable margin.
20 mm | 12.73 | 47.1 kg | 23.6 kg | Drives a caliper directly.
10 mm | 6.37 | 94.2 kg | 47.1 kg | Drum too small to build around the horn.

If it turns out weak

Change one number. Halving STROKE in the .scad halves the drum and doubles the pull. Nothing else in the model needs touching — every dimension is derived from it.

## 04 Assembly order

The order matters: the horn has to be on the servo before the drum goes over it, and the cables load last.

1. Print the fit coupon and check it on your horn.
  Five minutes. It should push on snug with no rotational play — slop here becomes brake slop later. If it is wrong, measure the horn and correct the four dimensions at the top of the .scad.
2. Screw the stock star horn onto the servo.
  Its factory centre screw, normal torque. This is the joint that carries all 30 kg·cm.
3. Drop the drum over the horn.
  The star pocket underneath swallows it. The pocket is rotated 45° from the nipple bores so nothing collides.
4. Retain it with M3 screws through the top slots.
  Two is enough, four is better. The slots run r = 8…19 mm, so whichever holes your horn has will line up with something.
5. Load the two cables.
  Nipple down its hole from the top face, wire out through the side slot into its groove. Wind both the same direction.

Not designed yet — you still need this

The drum only pulls the inner wire. The outer housing must be anchored to the aluminum plate at a fixed point, aimed tangentially at each groove level. Without those two stops the housing just compresses and nothing moves.

## 05 G-code, ready to run

Sliced for the Raise3D N2 in PLA. Two different profiles: the coupon is a throwaway gauge so it prints light and fast; the drum is structural, so it gets five walls and 55 % infill because the nipple pockets carry the whole cable load through their walls.

Print | Layer | Walls | Infill | Time | PLA
horn_fitcheck.gcode fit gauge — run this first | 0.25 | 3 | 15 % | 31 m | 6.6 g
servo_brake_drum.gcode the real part | 0.15 | 5 | 55 % | 3 h 35 m | 26.0 g

### Checked before handing over

- Toolpaths land 122–177 mm in X and Y — centred on the 300 × 300 bed, brim included
- Z tops out at 19.55 mm, matching the model
- Absolute E (M82), matching the N2's firmware
- No G29 — your N2 is levelled by hand, a probe command would crash it
- No support material and no overhang warnings from the slicer

Watch the first layer

The start and end G-code is generic Marlin, not Raise3D's official ideaMaker profile. It homes, heats, and lays a prime line along the front edge. Stay with it for the first layer the first time you run it.

PLA caveat

PLA creeps under sustained load and softens near 55 °C. If this holds the brake applied for long stretches, or lives in a closed enclosure, re-slice in PETG — same geometry.

Servo TD-8130MG · ~30 kg·cm · 25T Mesh: watertight · 1 shell Desktop\servo_brake_drum\

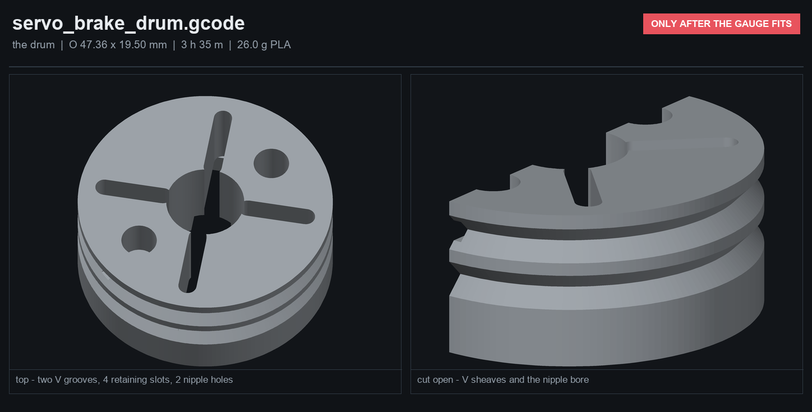
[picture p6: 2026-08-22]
design/servo_brake_drum.png

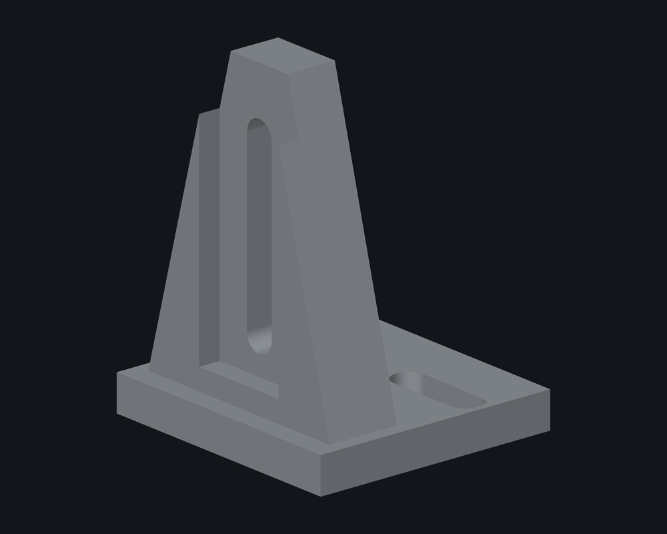
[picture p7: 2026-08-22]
design/view_stop_post.png

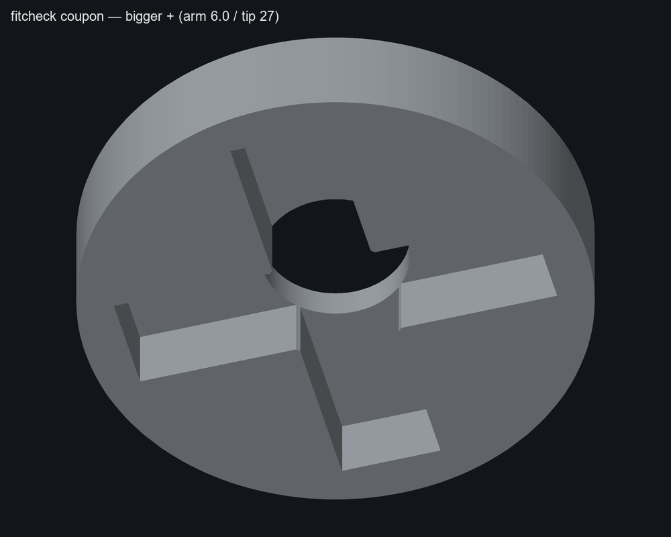
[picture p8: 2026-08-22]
design/mini_fit_isob.png

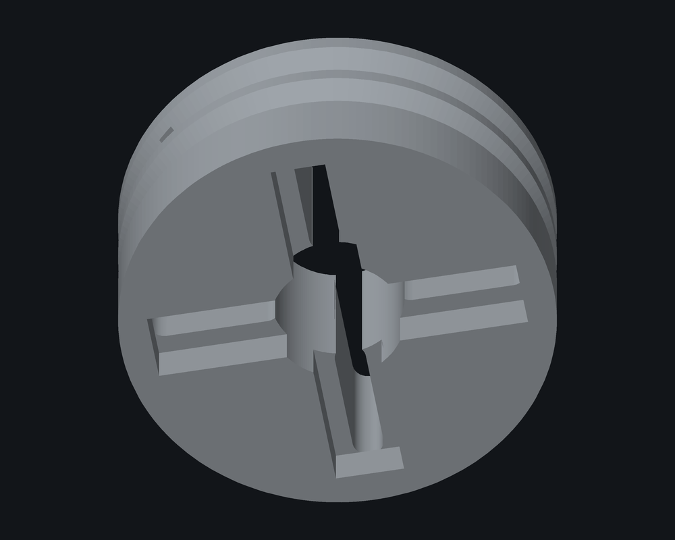
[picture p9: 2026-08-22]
design/view_bottom.png

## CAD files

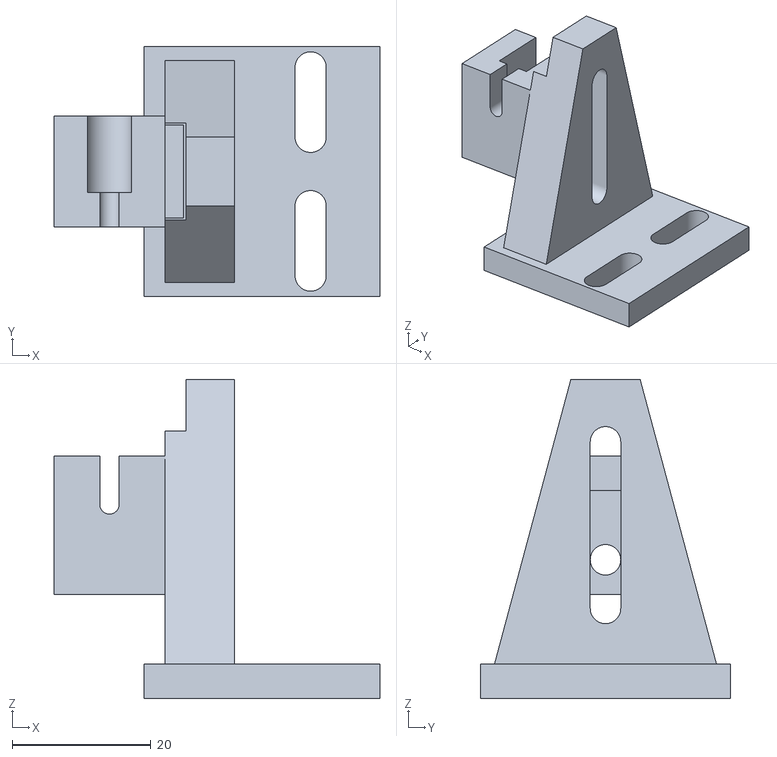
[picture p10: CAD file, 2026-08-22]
print/_stop_asm.stl
47.0 x 36.0 x 46.0

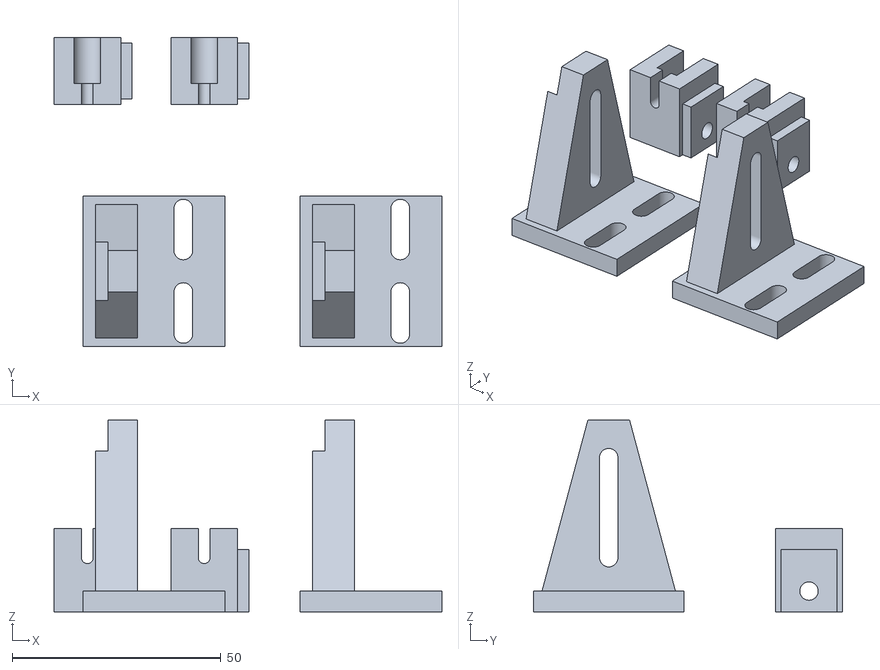
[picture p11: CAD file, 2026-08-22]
design/cable_stops_plate.stl
93.0 x 74.0 x 46.0

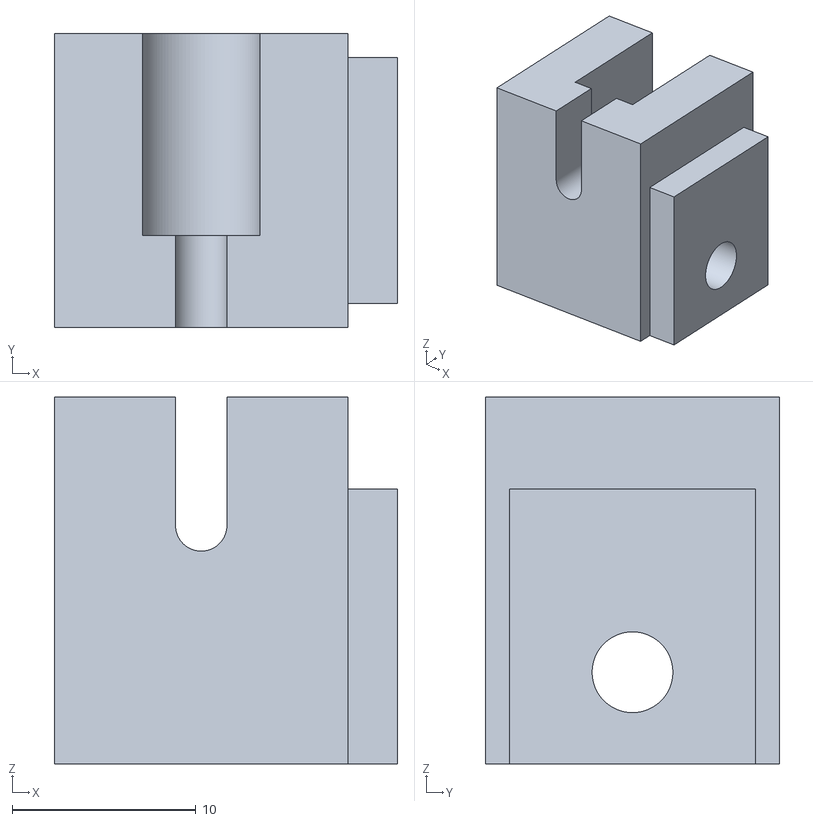
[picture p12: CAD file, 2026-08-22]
design/PRINT SERVO/cable_stop_block.stl
18.7 x 16.0 x 20.0

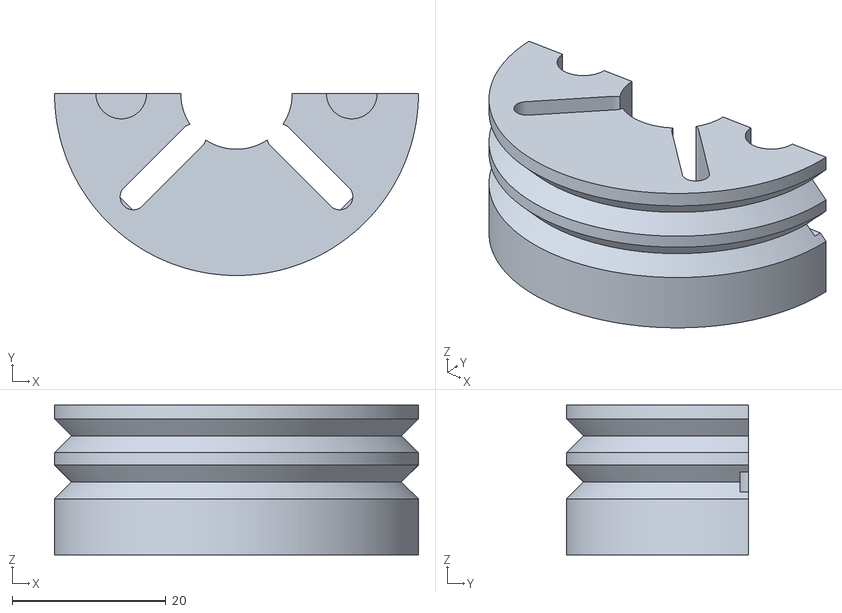
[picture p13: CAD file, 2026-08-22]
print/_cut.stl
47.4 x 23.7 x 19.5

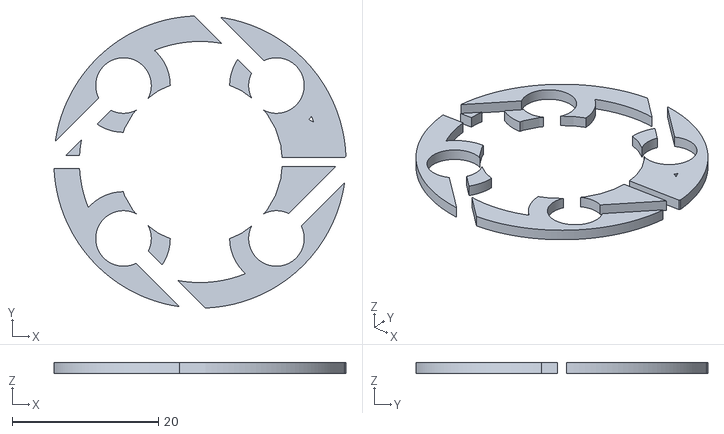
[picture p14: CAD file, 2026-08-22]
worm-wheel/cap_ctl.stl
40.0 x 40.0 x 1.50

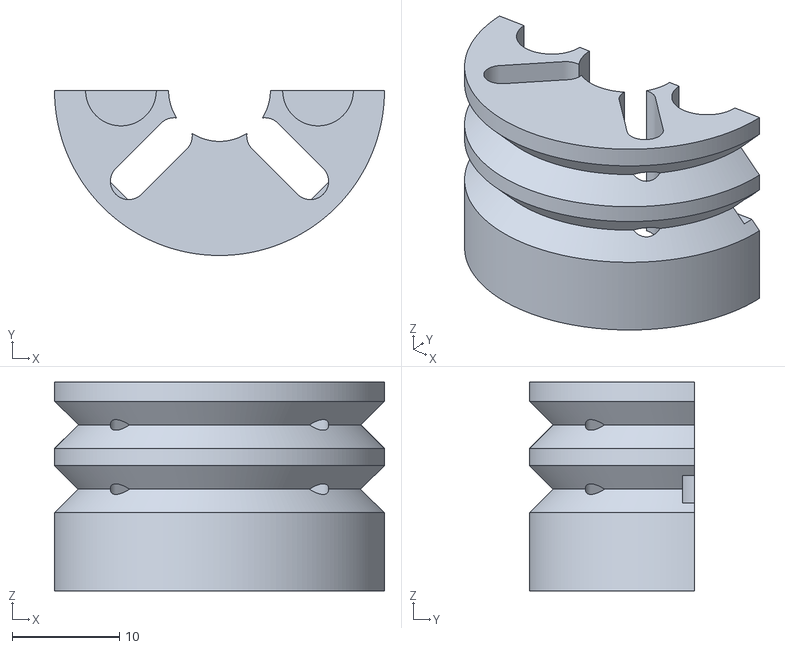
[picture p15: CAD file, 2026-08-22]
design/mini_cut.stl
30.8 x 15.4 x 19.5

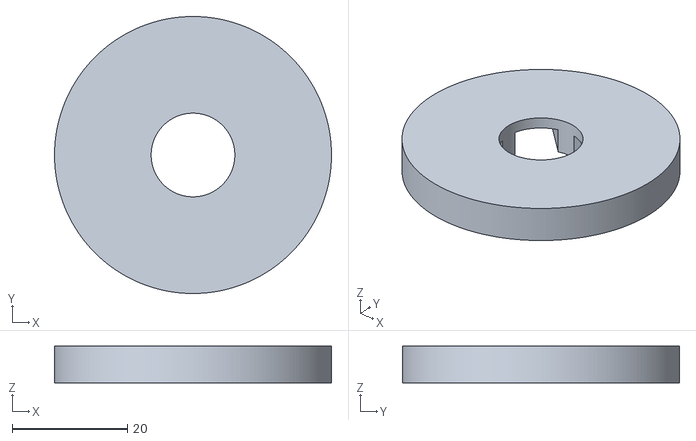
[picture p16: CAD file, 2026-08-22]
design/PRINT SERVO/horn_fitcheck.stl
48.0 x 48.0 x 6.40

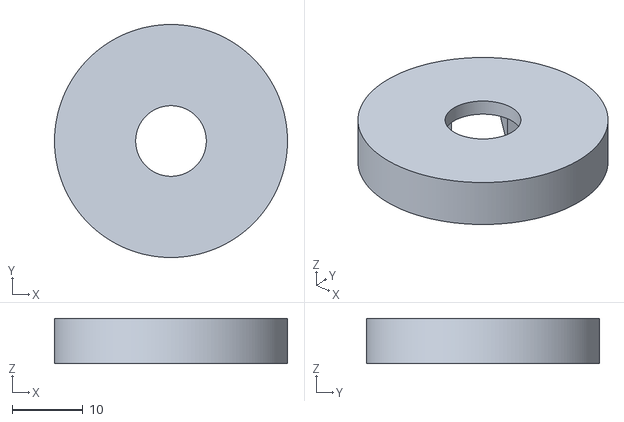
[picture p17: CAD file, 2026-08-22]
print/mini_fit.stl
33.0 x 33.0 x 6.40

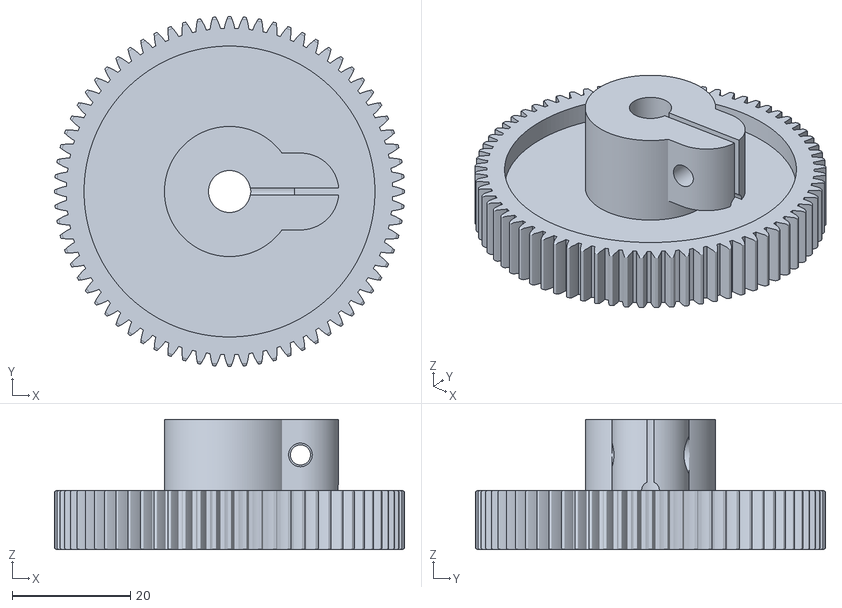
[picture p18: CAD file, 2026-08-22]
worm-wheel/gear60_z72_m0.8_spur.stl
59.2 x 59.2 x 22.0

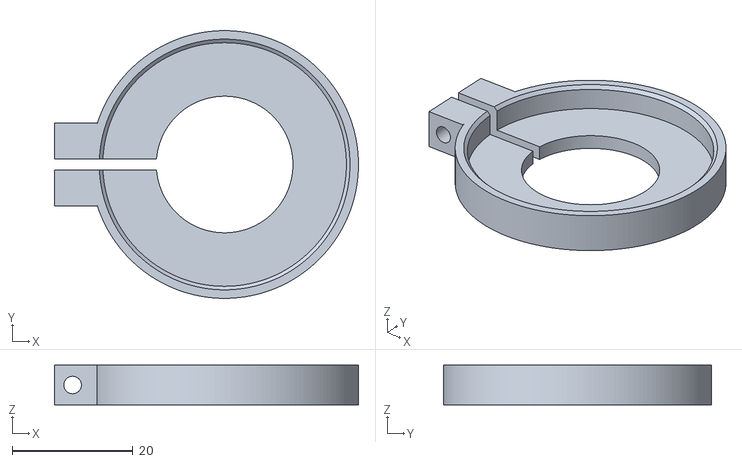
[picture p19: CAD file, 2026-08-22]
worm-wheel/cap60.stl
50.3 x 44.3 x 6.60

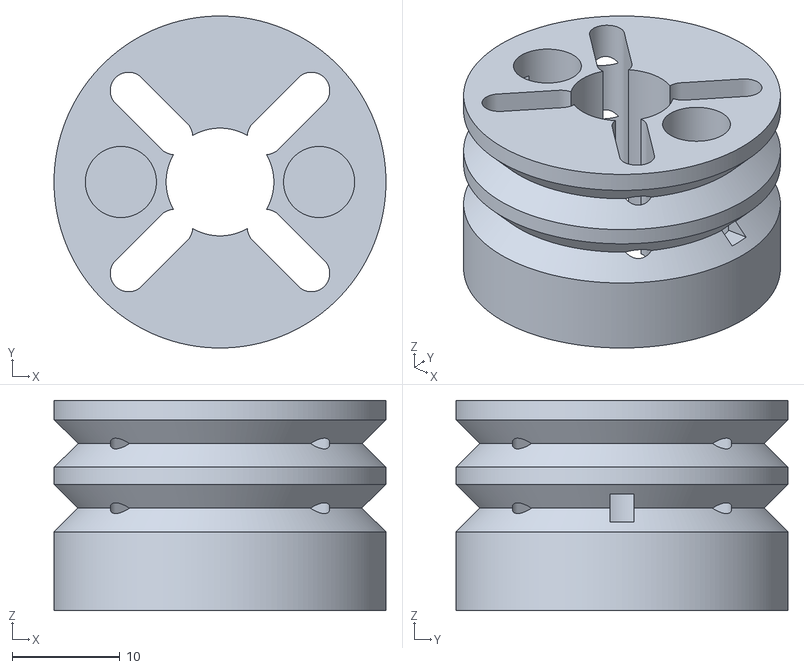
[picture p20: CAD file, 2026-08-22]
design/mini_drum.stl
30.8 x 30.8 x 19.5

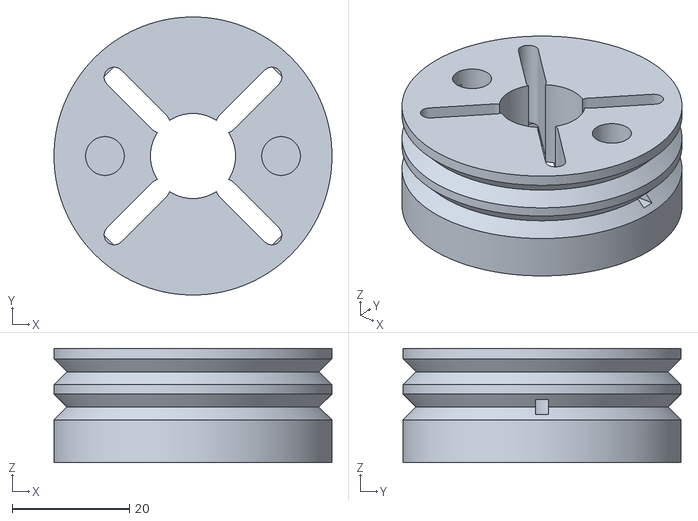
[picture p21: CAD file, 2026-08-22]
design/PRINT SERVO/servo_brake_drum.stl
47.4 x 47.4 x 19.5

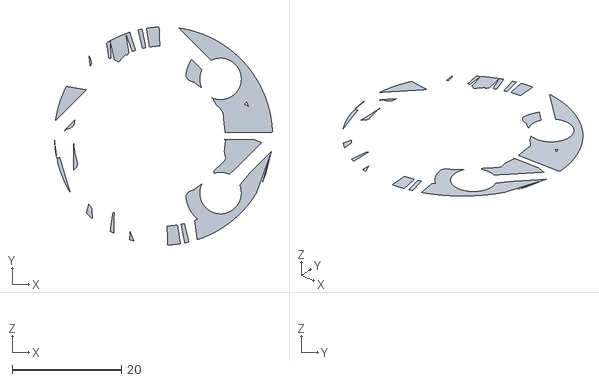
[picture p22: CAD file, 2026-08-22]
worm-wheel/v3_cap_fit.stl
40.0 x 40.0 x 0

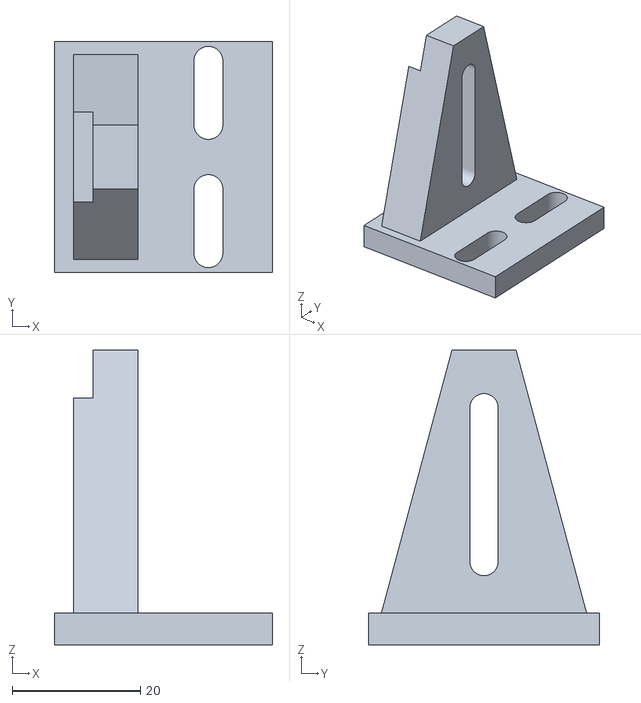
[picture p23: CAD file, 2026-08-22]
design/cable_stop_post.stl
34.0 x 36.0 x 46.0

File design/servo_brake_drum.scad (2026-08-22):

// ==============================================================
//   SERVO BRAKE-CABLE DRUM   —   TD-8130MG standard servo
//   Pulls TWO bicycle brake cables equally.
//   Stroke 70 mm per cable over 180 deg of servo rotation.
//
//   The stock 4-arm star horn is CAPTURED in a pocket underneath,
//   so the factory-moulded spline takes the torque, not printed PLA.
//
//   Rev B — printability fixes after slicing rev A:
//     * grooves are now 90 deg V-sheaves, not square channels.
//       A square groove left a 3 mm cantilever ring hanging in
//       mid-air above each groove ("collapsing overhang").
//       45 deg walls are self-supporting, and the cable seats
//       itself at exactly the design radius.
//     * the centre bore is now the same diameter as the horn
//       boss and runs right through. Before, the step between
//       the Ø9 bore and the Ø14.5 boss pocket left an
//       unsupported ring at the pocket ceiling
//       ("floating bridge anchors").
// ==============================================================

PART = "drum";      // "drum"  = the real part
                    // "fit"   = 6 mm test coupon, just the horn pocket
                    // "cut"   = half cut away, for looking inside

/* ---------------------------------------------------------------
   MEASURE THESE FOUR ON YOUR BLACK STAR HORN WITH CALIPERS
   The defaults are typical for a 25T 4-arm horn — verify them.
   --------------------------------------------------------------- */
HORN_TIP   = 40.0;   // tip-to-tip across one pair of arms
HORN_ARM_W =  7.0;   // width of an arm, measured near the tip
HORN_T     =  4.0;   // thickness of the horn arms
HORN_BOSS  = 14.0;   // diameter of the round centre boss

/* ---------------- drive geometry ---------------- */
STROKE   = 70;       // cable travel wanted, mm
SWEEP    = 180;      // servo rotation used, deg
CABLE_D  = 1.6;      // brake inner wire diameter
V_DEPTH  = 2.2;      // sheave depth. 45 deg walls, so this is also
                     // the half-width of the groove mouth.

/* ---------------- brake cable nipple ------------
   6.6 x 8.0  = flat-bar / MTB barrel nipple
   7.6 x 5.0  = drop-bar / road pear nipple        */
NIP_D = 6.6;
NIP_H = 8.0;

/* ---------------- fit & fasteners ---------------- */
CLR        = 0.25;   // pocket clearance on the horn (per side)
POCKET_CLR = 0.40;   // extra pocket depth
SCREW_D    = 3.4;    // M3 clearance, retaining screws into the horn holes
SHOW_SLOTS = true;   // radial retaining slots on top

$fn = 180;

/* ================= derived ================= */
D_EFF   = STROKE*360/(SWEEP*PI);   // cable centreline diameter
R_EFF   = D_EFF/2;
R_FLOOR = R_EFF - CABLE_D/2;       // V apex radius — the cable seats
                                   // where the V is CABLE_D wide, which
                                   // is exactly R_EFF. That is the point.
R_OUT   = R_FLOOR + V_DEPTH;       // outer radius

ZC1     = 9.5;                     // lower groove centre
ZC2     = 15.5;                    // upper groove centre
H_TOT   = 19.5;

Z_POCK  = HORN_T + POCKET_CLR;     // pocket ceiling
BORE_D  = HORN_BOSS + 2*CLR;       // centre bore == boss pocket, straight through
SLOT_W  = CABLE_D + 0.6;           // wire escape slot, width
SLOT_H  = 2.6;                     // ...and height. Keep != 2*V_DEPTH.
R_NIP   = 15.0;                    // nipple pocket centre radius
HORN_ROT= 45;                      // arms at 45/135/... so they miss the nipples

echo(str(">> cable centreline dia = ", D_EFF, " mm"));
echo(str(">> outer dia            = ", 2*R_OUT, " mm"));
echo(str(">> total height         = ", H_TOT, " mm"));
echo(str(">> rim between grooves  = ", (ZC2-V_DEPTH)-(ZC1+V_DEPTH), " mm"));

/* ================= modules ================= */

// The 4 arms of the star pocket. The centre is handled by the
// through bore, so there is no boss pocket to leave a floating ring.
module horn_arms(extra=0){
    w = HORN_ARM_W + 2*CLR + extra;
    l = HORN_TIP   + 2*CLR + extra;
    rotate([0,0,HORN_ROT])
        for(a=[0,90]) rotate([0,0,a])
            translate([-l/2,-w/2,-0.01]) cube([l,w,Z_POCK+0.01]);
}

// 90 deg V sheave, cut as a revolved triangle. Both faces sit at
// 45 deg, so nothing overhangs and no support is needed.
module v_groove(zc){
    translate([0,0,zc])
    rotate_extrude(convexity=6)
        polygon([[R_FLOOR, 0],
                 [R_OUT+2,  V_DEPTH+2],
                 [R_OUT+2, -V_DEPTH-2]]);
}

// nipple pocket + the side slot the wire escapes through
module cable_anchor(zc, ang){
    rotate([0,0,ang]){
        translate([R_NIP,0,zc-NIP_H/2])
            cylinder(d=NIP_D, h=H_TOT);              // open to the top face
        // slot half-height must NOT equal V_DEPTH, or its top edge lands
        // exactly on the groove mouth rim and CGAL emits coincident faces
        translate([R_NIP-1, -SLOT_W/2, zc-SLOT_H/2])
            cube([R_OUT-R_NIP+3, SLOT_W, SLOT_H]);
    }
}

module drum(){
    difference(){
        cylinder(r=R_OUT, h=H_TOT);

        v_groove(ZC1);
        v_groove(ZC2);

        // nipples 180 deg apart, so the two cable tensions form a
        // couple that cancels instead of a 132 N side load on the
        // servo bearing
        cable_anchor(ZC1,   0);
        cable_anchor(ZC2, 180);

        horn_arms();

        translate([0,0,-1]) cylinder(d=BORE_D, h=H_TOT+2);

        // retaining slots: M3 from the top into whichever hole of the
        // horn arm lines up. Slotted, so any hole pattern works.
        if(SHOW_SLOTS)
            for(a=[0,90,180,270]) rotate([0,0,HORN_ROT+a])
                hull(){
                    translate([ 8,0,Z_POCK]) cylinder(d=SCREW_D, h=H_TOT);
                    translate([19,0,Z_POCK]) cylinder(d=SCREW_D, h=H_TOT);
                }
    }
}

// quick coupon to test the horn fit before printing the real thing
module fitcheck(){
    h = Z_POCK + 2.0;
    difference(){
        cylinder(r = HORN_TIP/2 + 4, h = h);
        horn_arms();
        translate([0,0,-1]) cylinder(d=BORE_D, h=h+2);
    }
}

module cutaway(){
    difference(){
        drum();
        translate([-60,0,-1]) cube([120,60,H_TOT+2]);
    }
}

if     (PART == "drum") drum();
else if(PART == "cut" ) cutaway();
else                    fitcheck();

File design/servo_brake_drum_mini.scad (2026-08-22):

// ==============================================================
//   SERVO BRAKE-CABLE DRUM  —  MINI  (TD-8130MG, small cross horn)
//   Pulls TWO bicycle brake cables equally.
//   Ø28 cable centreline (outer Ø30.8). ~44 mm stroke / 180 deg.
//
//   Smaller sibling of servo_brake_drum.scad. Same proven Rev-B
//   anchor scheme (vertical nipple pocket inboard of the groove,
//   two stacked grooves 180 deg apart so the two 66 N pulls form
//   a couple, not a 132 N side-load), just rescaled for the
//   trimmed 25T cross horn shown in the 2026-07-23 photos.
//
//   WHY NOT Ø20:  below ~Ø28 the revolved groove undercuts the
//   material the nipple must seat against — the shoulder becomes
//   a <1 mm PLA sliver right where the 66 N pull lands. Ø28 is the
//   smallest diameter that still has a solid nipple anchor.
// ==============================================================

PART = "drum";      // "drum" = real part
                    // "fit"  = short coupon, just the horn pocket
                    // "cut"  = half cut away, to look inside

/* ---------------------------------------------------------------
   CROSS HORN — measured 2026-07-23 (TD-8130MG will use this horn,
   trimmed).  Arm LENGTH is set by HORN_TIP = the trim target;
   cut the arms so the cross is HORN_TIP mm tip-to-tip.
   --------------------------------------------------------------- */
HORN_TIP   = 27.0;   // TRIM TARGET: arm tip-to-tip after you cut them
HORN_ARM_W =  6.5;   // arm slot width (widened from measured 5.0 so the horn drops in)
HORN_T     =  4.0;   // measured horn thickness
HORN_BOSS  =  9.0;   // measured centre-boss (hub) diameter

/* ---------------- drive geometry ---------------- */
STROKE   = 44;       // cable travel, mm  -> D_EFF = 28.0
SWEEP    = 180;      // servo rotation used, deg
CABLE_D  = 1.6;      // brake inner wire diameter
V_DEPTH  = 2.2;      // sheave depth = half-width of the V mouth (45 deg walls)

/* ---------------- brake cable nipple ------------
   6.6 x 8.0 = flat-bar / MTB barrel nipple        */
NIP_D = 6.6;
NIP_H = 8.0;

/* ---------------- fit & fasteners ---------------- */
CLR        = 0.50;   // pocket clearance per side (0.25->0.5: horn wouldn't start in, elephant-foot at the down-facing mouth)
POCKET_CLR = 0.40;   // extra pocket depth
SCREW_D    = 3.4;    // M3 clearance, retaining screws into horn holes
SHOW_SLOTS = true;   // radial retaining slots on top

$fn = 180;

/* ================= derived ================= */
D_EFF   = STROKE*360/(SWEEP*PI);   // cable centreline diameter
R_EFF   = D_EFF/2;
R_FLOOR = R_EFF - CABLE_D/2;       // V apex radius (cable seats at R_EFF)
R_OUT   = R_FLOOR + V_DEPTH;       // outer radius

ZC1     = 9.5;                     // lower groove centre
ZC2     = 15.5;                    // upper groove centre
H_TOT   = 19.5;

Z_POCK  = HORN_T + POCKET_CLR;     // pocket ceiling
BORE_D  = HORN_BOSS + 2*CLR;       // centre bore == boss clearance, straight through
SLOT_W  = CABLE_D + 0.6;           // wire escape slot width
SLOT_H  = 2.6;                     // ...and height. Keep != 2*V_DEPTH (CGAL coincidence trap)
R_NIP   = 9.2;                     // nipple pocket centre radius (inboard of groove floor)
HORN_ROT= 45;                      // arms at 45/135/... so they miss the 0/180 nipples

echo(str(">> cable centreline dia = ", D_EFF, " mm"));
echo(str(">> outer dia            = ", 2*R_OUT, " mm"));
echo(str(">> total height         = ", H_TOT, " mm"));
echo(str(">> nipple pocket r      = ", R_NIP, "  bore r = ", BORE_D/2,
         "  groove floor r = ", R_FLOOR));
echo(str(">> wall nipple->bore    = ", (R_NIP-NIP_D/2)-(BORE_D/2), " mm"));
echo(str(">> wall nipple->floor   = ", R_FLOOR-(R_NIP+NIP_D/2), " mm"));

/* ================= modules ================= */

// 4 arms of the cross pocket. Centre handled by the through bore,
// so no floating boss-pocket ceiling.
module horn_arms(extra=0){
    w = HORN_ARM_W + 2*CLR + extra;
    l = HORN_TIP   + 2*CLR + extra;
    rotate([0,0,HORN_ROT])
        for(a=[0,90]) rotate([0,0,a])
            translate([-l/2,-w/2,-0.01]) cube([l,w,Z_POCK+0.01]);
}

// 90 deg V sheave, revolved triangle -> self-supporting, no support
module v_groove(zc){
    translate([0,0,zc])
    rotate_extrude(convexity=6)
        polygon([[R_FLOOR, 0],
                 [R_OUT+2,  V_DEPTH+2],
                 [R_OUT+2, -V_DEPTH-2]]);
}

// nipple pocket (drops in from the top) + radial wire escape slot
module cable_anchor(zc, ang){
    rotate([0,0,ang]){
        translate([R_NIP,0,zc-NIP_H/2])
            cylinder(d=NIP_D, h=H_TOT);              // open to top face
        // slot half-height != V_DEPTH so its top edge doesn't land on
        // the groove mouth rim (CGAL coincident-face trap)
        translate([R_NIP-1, -SLOT_W/2, zc-SLOT_H/2])
            cube([R_OUT-R_NIP+3, SLOT_W, SLOT_H]);
    }
}

module drum(){
    difference(){
        cylinder(r=R_OUT, h=H_TOT);

        v_groove(ZC1);
        v_groove(ZC2);

        cable_anchor(ZC1,   0);
        cable_anchor(ZC2, 180);

        horn_arms();

        translate([0,0,-1]) cylinder(d=BORE_D, h=H_TOT+2);

        // retaining slots: M3 from top into whichever horn hole lines up
        if(SHOW_SLOTS)
            for(a=[0,90,180,270]) rotate([0,0,HORN_ROT+a])
                hull(){
                    translate([ 6,0,Z_POCK]) cylinder(d=SCREW_D, h=H_TOT);
                    translate([12,0,Z_POCK]) cylinder(d=SCREW_D, h=H_TOT);
                }
    }
}

// coupon to test the trimmed-horn fit before printing the whole drum
module fitcheck(){
    h = Z_POCK + 2.0;
    difference(){
        cylinder(r = HORN_TIP/2 + 3, h = h);
        horn_arms();
        translate([0,0,-1]) cylinder(d=BORE_D, h=h+2);
    }
}

module cutaway(){
    difference(){
        drum();
        translate([-60,0,-1]) cube([120,60,H_TOT+2]);
    }
}

if     (PART == "drum") drum();
else if(PART == "cut" ) cutaway();
else                    fitcheck();

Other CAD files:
design/cable_stop.scad
design/mini_both.scad
print/cable_stop.scad
print/mini_both.scad
worm-wheel/_cap_preview.scad
worm-wheel/_v2_sandbox.scad
worm-wheel/_v3_half.scad
worm-wheel/_v3_sections.scad
worm-wheel/_v3_views.scad
worm-wheel/_views.scad
worm-wheel/cap60.scad
worm-wheel/cap_fit.stl
worm-wheel/gear60.scad
worm-wheel/gear60_d608.scad
worm-wheel/gear60_d62.scad
worm-wheel/gear60_v2.scad
worm-wheel/gear60_v3.scad
worm-wheel/section.scad
worm-wheel/test_cable_route.scad
worm-wheel/test_cap_fit.scad
worm-wheel/test_cap_fit_v3.scad
worm-wheel/test_clamp.scad
worm-wheel/v3_cap_ctl.stl

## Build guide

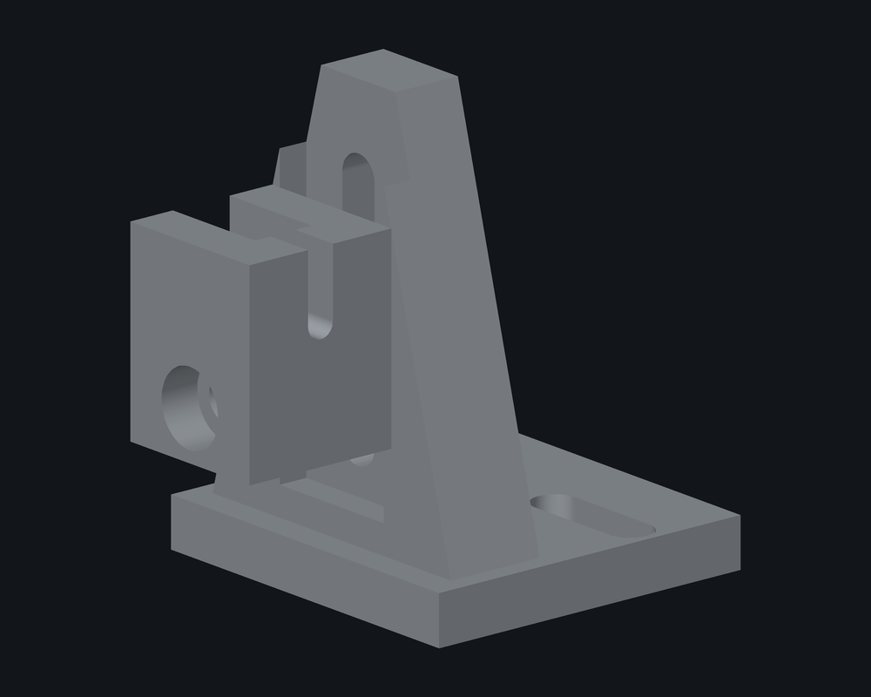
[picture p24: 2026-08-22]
print/view_stop_asm.png

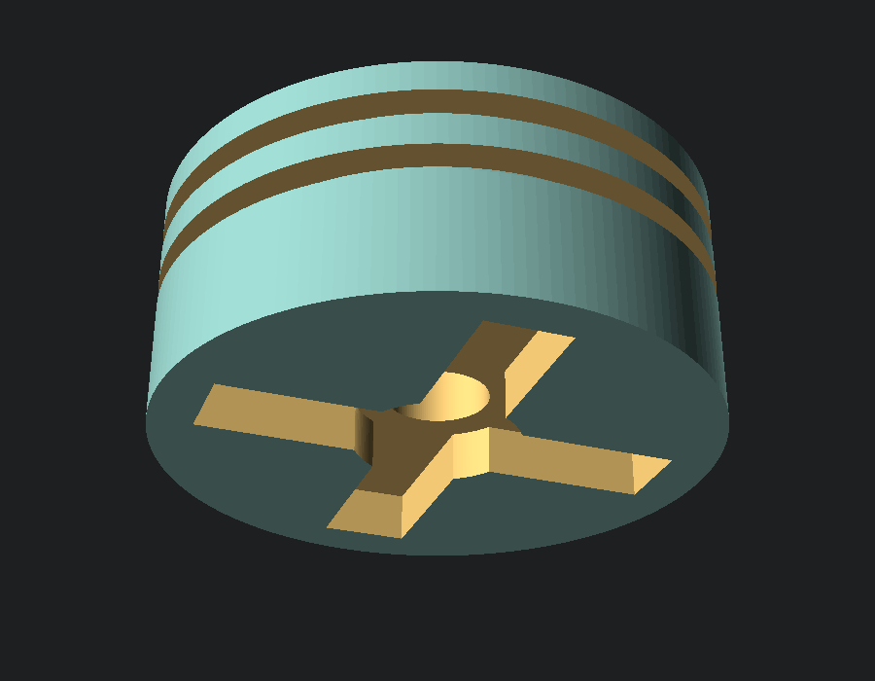
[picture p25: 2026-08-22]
print/preview_bottom.png

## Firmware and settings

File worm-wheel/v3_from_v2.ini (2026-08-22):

arc_fitting = disabled
autoemit_temperature_commands = 1
automatic_extrusion_widths = 0
automatic_infill_combination = 0
automatic_infill_combination_max_layer_height = 100%
avoid_crossing_curled_overhangs = 0
avoid_crossing_perimeters = 0
avoid_crossing_perimeters_max_detour = 0
bed_shape = 0x0,300x0,300x300,0x300
bed_temperature = 80
bed_temperature_extruder = 0
before_layer_gcode = 
between_objects_gcode = 
binary_gcode = 0
bottom_fill_pattern = monotonic
bottom_solid_layers = 4
bottom_solid_min_thickness = 0
bridge_acceleration = 0
bridge_angle = 0
bridge_fan_speed = 100
bridge_flow_ratio = 1
bridge_speed = 60
brim_separation = 0
brim_type = outer_only
brim_width = 0
chamber_minimal_temperature = 0
chamber_temperature = 0
color_change_gcode = M600
colorprint_heights = 
complete_objects = 0
cooling = 1
cooling_perimeter_transition_distance = 0
cooling_slowdown_logic = uniform_cooling
cooling_tube_length = 5
cooling_tube_retraction = 91.5
custom_parameters_filament = ""
custom_parameters_print = 
custom_parameters_printer = 
default_acceleration = 0
deretract_speed = 0
disable_fan_first_layers = 3
dont_support_bridges = 1
draft_shield = disabled
duplicate_distance = 6
elefant_foot_compensation = 0
enable_dynamic_fan_speeds = 0
enable_dynamic_overhang_speeds = 0
end_filament_gcode = "; Filament-specific end gcode \n;END gcode for filament\n"
end_gcode = M104 S0 ; turn off temperature\nG28 X0  ; home X axis\nM84     ; disable motors\n
ensure_vertical_shell_thickness = enabled
external_perimeter_acceleration = 0
external_perimeter_extrusion_width = 0
external_perimeter_speed = 50%
external_perimeters_first = 0
extra_loading_move = -2
extra_perimeters = 1
extra_perimeters_on_overhangs = 0
extruder_clearance_height = 20
extruder_clearance_radius = 20
extruder_colour = ""
extruder_offset = 0x0
extrusion_axis = E
extrusion_multiplier = 1
extrusion_width = 0
fan_always_on = 0
fan_below_layer_time = 60
filament_abrasive = 0
filament_colour = #29B2B2
filament_cooling_final_speed = 3.4
filament_cooling_initial_speed = 2.2
filament_cooling_moves = 4
filament_cost = 0
filament_density = 0
filament_diameter = 1.75
filament_flush_speed = 0
filament_flush_volume = 0
filament_infill_max_crossing_speed = 0
filament_infill_max_speed = 0
filament_load_time = 0
filament_loading_speed = 28
filament_loading_speed_start = 3
filament_max_volumetric_speed = 0
filament_minimal_purge_on_wipe_tower = 15
filament_multitool_ramming = 0
filament_multitool_ramming_flow = 10
filament_multitool_ramming_volume = 10
filament_notes = ""
filament_purge_multiplier = 100%
filament_ramming_parameters = "120 100 6.6 6.8 7.2 7.6 7.9 8.2 8.7 9.4 9.9 10.0| 0.05 6.6 0.45 6.8 0.95 7.8 1.45 8.3 1.95 9.7 2.45 10 2.95 7.6 3.45 7.6 3.95 7.6 4.45 7.6 4.95 7.6"
filament_seam_gap_distance = 15%
filament_settings_id = ""
filament_shrinkage_compensation_xy = 0%
filament_shrinkage_compensation_z = 0%
filament_soluble = 0
filament_spool_weight = 0
filament_stamping_distance = 0
filament_stamping_loading_speed = 20
filament_toolchange_delay = 0
filament_type = PETG
filament_unload_time = 0
filament_unloading_speed = 90
filament_unloading_speed_start = 100
fill_angle = 45
fill_density = 40%
fill_pattern = stars
first_layer_acceleration = 0
first_layer_acceleration_over_raft = 0
first_layer_bed_temperature = 80
first_layer_extrusion_width = 200%
first_layer_height = 0.24
first_layer_infill_speed = 0
first_layer_speed = 30
first_layer_speed_over_raft = 30
first_layer_temperature = 245
full_fan_speed_layer = 0
fuzzy_skin = none
fuzzy_skin_point_dist = 0.8
fuzzy_skin_thickness = 0.3
gap_fill_enabled = 1
gap_fill_speed = 20
gcode_comments = 0
gcode_flavor = reprap
gcode_label_objects = disabled
gcode_resolution = 0.0125
gcode_substitutions = 
high_current_on_filament_swap = 0
idle_temperature = nil
infill_acceleration = 0
infill_anchor = 600%
infill_anchor_max = 50
infill_every_layers = 1
infill_extruder = 1
infill_extrusion_width = 0
infill_first = 0
infill_overlap = 25%
infill_speed = 80
interface_shells = 0
interlocking_beam = 0
interlocking_beam_layer_count = 2
interlocking_beam_width = 0.8
interlocking_boundary_avoidance = 2
interlocking_depth = 2
interlocking_orientation = 22.5
ironing = 0
ironing_flowrate = 15%
ironing_spacing = 0.1
ironing_speed = 15
ironing_type = top
layer_gcode = 
layer_height = 0.16
machine_limits_usage = time_estimate_only
machine_max_acceleration_e = 10000,5000
machine_max_acceleration_extruding = 1500,1250
machine_max_acceleration_retracting = 1500,1250
machine_max_acceleration_travel = 1500,1250
machine_max_acceleration_x = 9000,1000
machine_max_acceleration_y = 9000,1000
machine_max_acceleration_z = 500,200
machine_max_feedrate_e = 120,120
machine_max_feedrate_x = 500,200
machine_max_feedrate_y = 500,200
machine_max_feedrate_z = 12,12
machine_max_jerk_e = 2.5,2.5
machine_max_jerk_x = 10,10
machine_max_jerk_y = 10,10
machine_max_jerk_z = 0.2,0.4
machine_max_junction_deviation = 0,0
machine_min_extruding_rate = 0,0
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

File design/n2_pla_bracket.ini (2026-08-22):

# PrusaSlicer config - Raise3D N2 (300x300x300), PLA
# BRACKET profile: cable housing stops.
# Walls matter far more than infill for a part loaded in bending,
# so this keeps 5 perimeters but drops infill to 40% to save time.
printer_technology = FFF
gcode_flavor = marlin
bed_shape = 0x0,300x0,300x300,0x300
max_print_height = 300
nozzle_diameter = 0.4
z_offset = 0
use_relative_e_distances = 0
use_firmware_retraction = 0
retract_length = 1
retract_speed = 40
deretract_speed = 40
retract_lift = 0.2
retract_before_travel = 2

filament_diameter = 1.75
filament_type = PLA
filament_density = 1.24
temperature = 205
first_layer_temperature = 210
bed_temperature = 60
first_layer_bed_temperature = 60
fan_always_on = 1
min_fan_speed = 100
max_fan_speed = 100
disable_fan_first_layers = 1
slowdown_below_layer_time = 12
min_print_speed = 10

layer_height = 0.20
first_layer_height = 0.20
perimeters = 5
top_solid_layers = 5
bottom_solid_layers = 4
fill_density = 40%
fill_pattern = gyroid
top_fill_pattern = monotonic
ensure_vertical_shell_thickness = 1
thin_walls = 1

skirts = 0
brim_width = 4
support_material = 0
raft_layers = 0

overhangs = 1
bridge_speed = 25

perimeter_speed = 35
external_perimeter_speed = 28
small_perimeter_speed = 20
infill_speed = 65
solid_infill_speed = 55
top_solid_infill_speed = 30
travel_speed = 120
first_layer_speed = 20

start_gcode = G90\nM82\nM140 S[first_layer_bed_temperature]\nM104 S[first_layer_temperature]\nG28\nM190 S[first_layer_bed_temperature]\nM109 S[first_layer_temperature]\nG92 E0\nG1 Z0.2 F3000\nG1 X6 Y6 F3000\nG1 X160 Y6 E12 F1200\nG1 X160 Y6.6 E12.6 F1200\nG1 X6 Y6.6 E24 F1200\nG92 E0\nG1 Z1 F3000
end_gcode = M104 S0\nM140 S0\nG91\nG1 E-2 F1800\nG1 Z10 F3000\nG90\nG1 X0 Y300 F6000\nM84

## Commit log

2026-08-22 Fail-Safe Servo Brake Actuator
    [_cap_preview.scad, _cut.stl, _stop_asm.stl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]
2026-08-22 Correct brake attribution; document the final worm-wheel drum
    The electrical hold-brake that caught fire was the team's work, not mine.
    My contribution is the mechanical replacement. Adds gear60_v3, the printed
    Bosch window-lift worm wheel carrying the four-cable drum, and states its
    +1.60 mm worm centre-distance shift as an open constraint.
